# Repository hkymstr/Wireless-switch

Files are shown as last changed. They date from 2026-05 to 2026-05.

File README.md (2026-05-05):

# Wireless Race Car Switch System — Hardware v2 (WiFi)

A fully wireless switch panel for a race car using two **Raspberry Pi Pico 2 W** boards.  
One board acts as the **Transmitter** (switch panel), the other as the **Receiver** (12 V output driver).

> **Bluetooth version:** see the `bluetooth` branch.

---

## System Overview

```
 ┌──────────────────────────┐      WiFi (AP/STA)      ┌─────────────────────────────┐
 │      TRANSMITTER         │ ◄──── UDP 20 Hz ──────► │        RECEIVER             │
 │    Raspberry Pi Pico 2W  │                          │    Raspberry Pi Pico 2W     │
 │                          │  Web UI: 192.168.4.1     │  Web UI: <RX-IP>            │
 │  GPIO 1-5 ← 5 switches   │                          │  GPIO 8-11 → 4× MOSFET     │
 │  GPIO 0  → Connected LED │                          │  GPIO 12   → Relay K2      │
 │  GPIO 7  → Searching LED │                          │  GPIO 0    → Connected LED  │
 │  Powered from 12 V via   │                          │  GPIO 7    → Searching LED  │
 │  on-board 5 V regulator  │                          │  Takes 12 V from car        │
 └──────────────────────────┘                          └─────────────────────────────┘
```

TX creates an **open WiFi access point** (`WirelessSwitch-1` by default). RX connects as a station.  
Both boards host a **web settings page** — join the WiFi network and open a browser to configure.

---

## Web Interface

| Board | URL | What you can change |
|---|-----|---|
| TX | `http://192.168.4.1` | Pair ID |
| RX | `http://<RX-IP>` (linked from TX page) | Pair ID, hold time, channel modes |

Connect any phone or laptop to the `WirelessSwitch-N` WiFi network (no password), then open the URL above. Settings are saved to flash and survive power cycles.

---

## GPIO Pin Mapping — Hardware v2

### Status LEDs (identical on both boards)

| GPIO | Function | Behaviour |
|---|---|---|
|  0 | CONNECTED LED | Solid ON when wireless link is up |
|  7 | SEARCHING LED | Flashes 2 Hz while searching; OFF when linked |

### Transmitter — Switch Inputs

Switches are **active-low** (connect switch between GPIO pin and GND).  
Internal pull-ups enabled in firmware.

| GPIO | Channel | Description |
|---|---|---|
|  1 | SW1 | Switch 1 input |
|  2 | SW2 | Switch 2 input |
|  3 | SW3 | Switch 3 input |
|  4 | SW4 | Switch 4 input |
|  5 | SW5 | Switch 5 input |

### Receiver — Output Channels

Outputs are **active-high** (GPIO HIGH = output energised).

| GPIO | Channel | Type | Max Load |
|---|---|---|---|
|  8 | CH1 | N-ch MOSFET | 5 A @ 12 V |
|  9 | CH2 | N-ch MOSFET | 5 A @ 12 V |
| 10 | CH3 | N-ch MOSFET | 5 A @ 12 V |
| 11 | CH4 | N-ch MOSFET | 5 A @ 12 V |
| 12 | CH5 | Relay K2 (SPDT) | Per relay rating |

---

## Repository Structure

```
├── kicad/
│   ├── wireless_switch.kicad_pro   KiCad project file
│   ├── wireless_switch.kicad_sch   Top-level schematic
│   ├── Pico_interface.kicad_sch    Pico 2 W GPIO interface sub-sheet
│   ├── analog_in.kicad_sch         Output channel sub-sheet (MOSFET + relay)
│   ├── input_power.kicad_sch       12 V → 5 V power supply sub-sheet
│   ├── wireless_switch.kicad_pcb   PCB layout
│   └── sym-lib-table               KiCad symbol library table
│
├── firmware/
│   ├── config.py        Shared configuration (defaults – overridden by web UI)
│   ├── tx_main.py       Transmitter MicroPython firmware
│   ├── rx_main.py       Receiver MicroPython firmware
│   ├── install_tx.bat   Windows transmitter installer  (default COM3)
│   ├── install_rx.bat   Windows receiver installer     (default COM5)
│   ├── install_tx.sh    Linux / macOS transmitter installer
│   ├── install_rx.sh    Linux / macOS receiver installer
│   ├── verify.bat       18-point verification script (Windows)
│   ├── led_test.bat     LED blink test (Windows)
│   └── polarity_test.bat  LED polarity / GPIO finder (Windows)
│
└── docs/
    └── wireless_switch.pdf   Full schematic PDF
```

---

## Hardware Requirements

### Per Board (× 2)
- Raspberry Pi Pico 2 W
- PCB from `kicad/wireless_switch.kicad_pcb`

### Transmitter PCB BOM additions
- 5× panel-mount toggle switches (SPDT or SPST)
- 2× LEDs with 330 Ω series resistors for GPIO 0 & 7
- 12 V → 5 V onboard regulator + capacitors (see `input_power.kicad_sch`)

### Receiver PCB BOM additions
- 4× N-channel logic-level MOSFETs (e.g. IRLZ44N) with gate resistors
- 1× 12 V SPDT relay K2 (Omron G5V-1 or equivalent)
- Relay driver transistor + flyback diodes
- Fusing on each output channel

---

## Software Installation

### Step 1 — Flash MicroPython to each Pico 2 W

1. Download the **Pico 2 W** MicroPython UF2 from  
   `https://micropython.org/download/RPI_PICO2_W/`
2. Hold **BOOTSEL**, plug USB → Pico appears as `RPI-RP2` mass storage
3. Drag the `.uf2` onto the drive — Pico reboots automatically

### Step 2 — Install `mpremote`

```bash
pip install mpremote
```

### Step 3 — Install Transmitter firmware

**Windows** (default COM3):
```bat
cd firmware
install_tx.bat
install_tx.bat COM4    ← specify a different port if needed
```

**Linux / macOS:**
```bash
cd firmware
chmod +x install_tx.sh && ./install_tx.sh
```

Confirm: board blinks SEARCHING LED **3× quickly** then flashes slowly.

### Step 4 — Install Receiver firmware

**Windows** (default COM5):
```bat
install_rx.bat
```

**Linux / macOS:**
```bash
./install_rx.sh
```

### Step 5 — Verify (optional, Windows)

```bat
verify.bat COM3 COM5
led_test.bat COM3 COM5
```

---

## Operation

1. **Power on both boards.** Both blink the SEARCHING LED **3× quickly** to confirm firmware is running.
2. TX creates an open WiFi access point. Both boards flash their SEARCHING LED while waiting for a link.
3. Once linked, **CONNECTED LED turns solid** on both boards; SEARCHING LED turns off.
4. Pressing a switch on TX activates the corresponding output on RX according to that channel's mode.
5. **On link loss:** RX holds its last output states for the configured hold time (default 10 s), then turns all outputs off. Both boards resume searching.

### Link Parameters

| Parameter | Value |
|---|---|
| Update rate | 20 Hz (every 50 ms) |
| Link timeout | 2 s |
| Hold on disconnect  | 10 s (configurable) |
| Protocol | UDP port 4210 |
| WiFi mode | TX = AP, RX = Station  |
| Network | Open (no password) |

---

## Channel Modes

Each output channel can be set independently via the RX web interface:

| Mode | Behaviour |
|---|---|
| Momentary | Output ON while switch is held; OFF when released |
| Latch | First press turns output ON; next press turns it OFF |

Latch state is preserved through brief disconnects (within hold window).  
A disconnection longer than the hold time resets all latch states to OFF.

---

## Multiple Pairs

If two TX/RX pairs operate at the same time, each pair needs a unique **Pair ID** so they don't cross-connect.

Set the same Pair ID on both boards in a pair via the web interface:

| Pair | TX SSID | RX connects to  |
|---|---|---|
|  1 | WirelessSwitch-1 | WirelessSwitch-1 |
|  2 | WirelessSwitch-2 | WirelessSwitch-2 |

**Procedure for changing Pair ID:**
1. Connect to the current WiFi network
2. Open RX settings → change Pair ID → Save (RX reboots, now looks for new SSID)
3. Open TX settings (192.168.4.1) → change Pair ID → Save (TX reboots with new SSID)
4. RX reconnects automatically

---

## Troubleshooting

| Symptom | Likely cause | Fix |
|---|---|-----|
| No 3× startup blink | Firmware not installed | Re-run the installer; verify MicroPython UF2 was flashed first |
| SEARCHING LED never stops flashing | Wrong Pair ID or TX not powered | Check both boards have the same Pair ID; confirm TX SEARCHING LED is also flashing |
| TX AP has stale WPA2 password | Old security settings cached in chip | Firmware resets the AP before configuring — power-cycle TX |
| Can't open web interface | Not connected to WirelessSwitch-N WiFi | Join the WiFi network first (no password), then open the URL |
| RX web page not reachable | RX IP unknown | Open TX page (192.168.4.1) first — it shows a clickable link to the RX page |
| Outputs don't activate | Wrong firmware on board | Confirm TX has `tx_main.py` installed as `main.py` |
| Latch output stuck after reboot | Expected — latch state is in RAM only | Press the switch once to toggle off |
| `mpremote` cannot find device | Driver missing or wrong port | Run `python -m mpremote connect list` |
| Pico not detected as storage | Not holding BOOTSEL | Hold BOOTSEL before plugging USB |

---

## Protocol Reference

UDP packet format (7 bytes, TX → RX, port 4210):

```
Byte 0   : 0xAA  (start marker)
Byte 1   : Switch 1 state  (0 = open, 1 = pressed)
Byte 2   : Switch 2 state
Byte 3   : Switch 3 state
Byte 4   : Switch 4 state
Byte 5   : Switch 5 state
Byte 6   : Checksum  = (SW1+SW2+SW3+SW4+SW5) & 0xFF
```

RX → TX heartbeat: `b"RXHERE"` (6 bytes, every 50 ms) — tells TX the RX's IP address.

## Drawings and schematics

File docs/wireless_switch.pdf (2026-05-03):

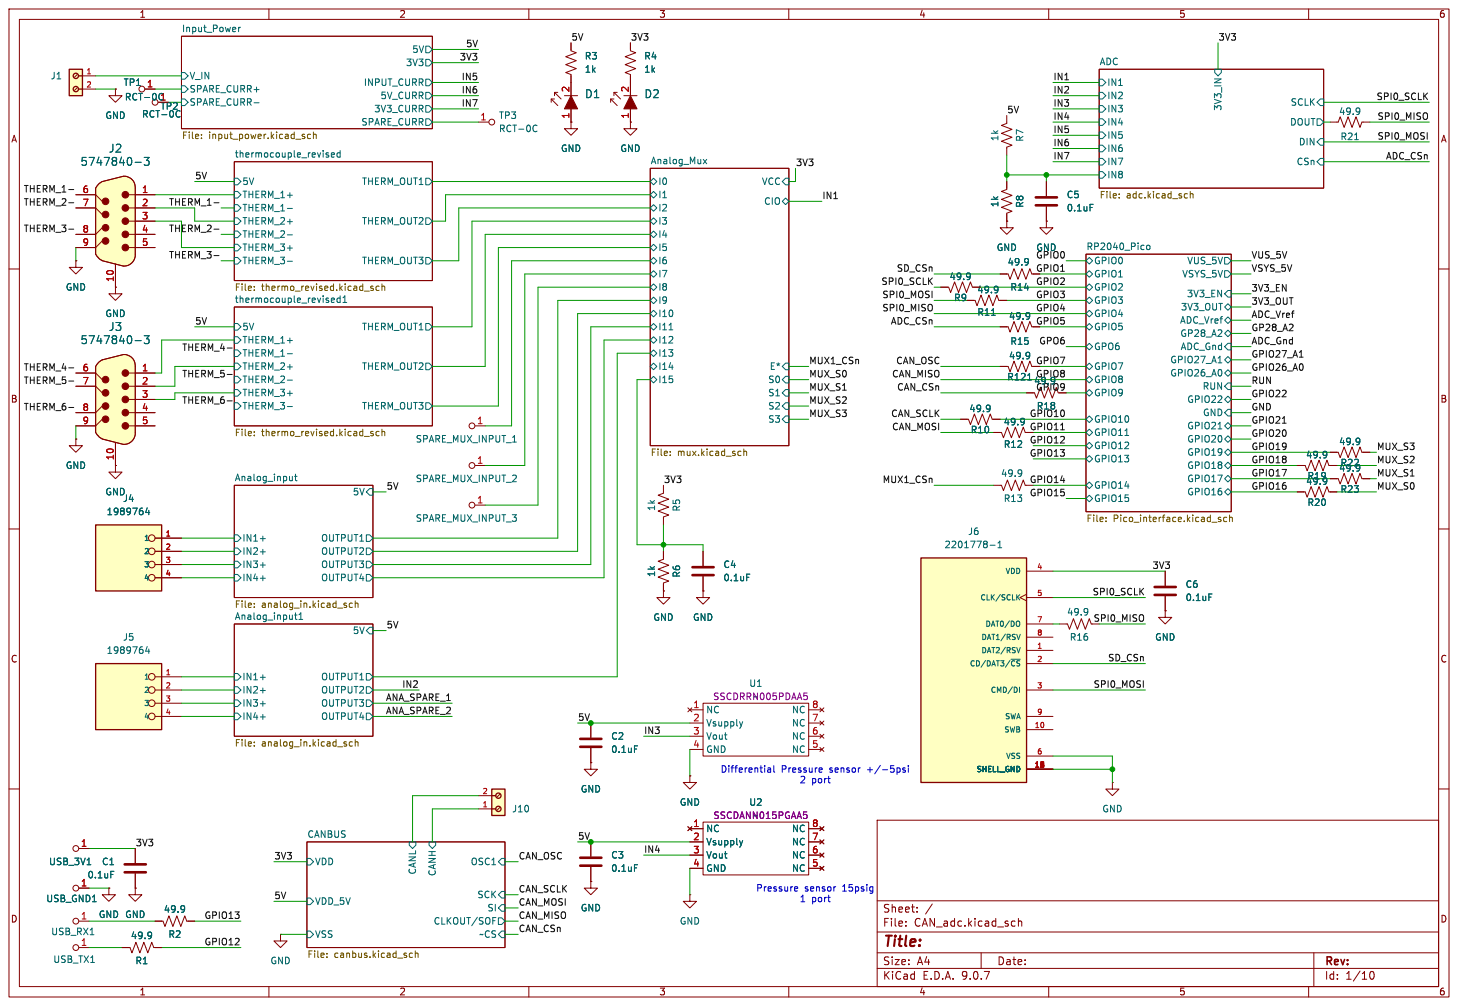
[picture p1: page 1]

Id: 1/10 Title: File: CAN_adc.kicad_sch Sheet: /

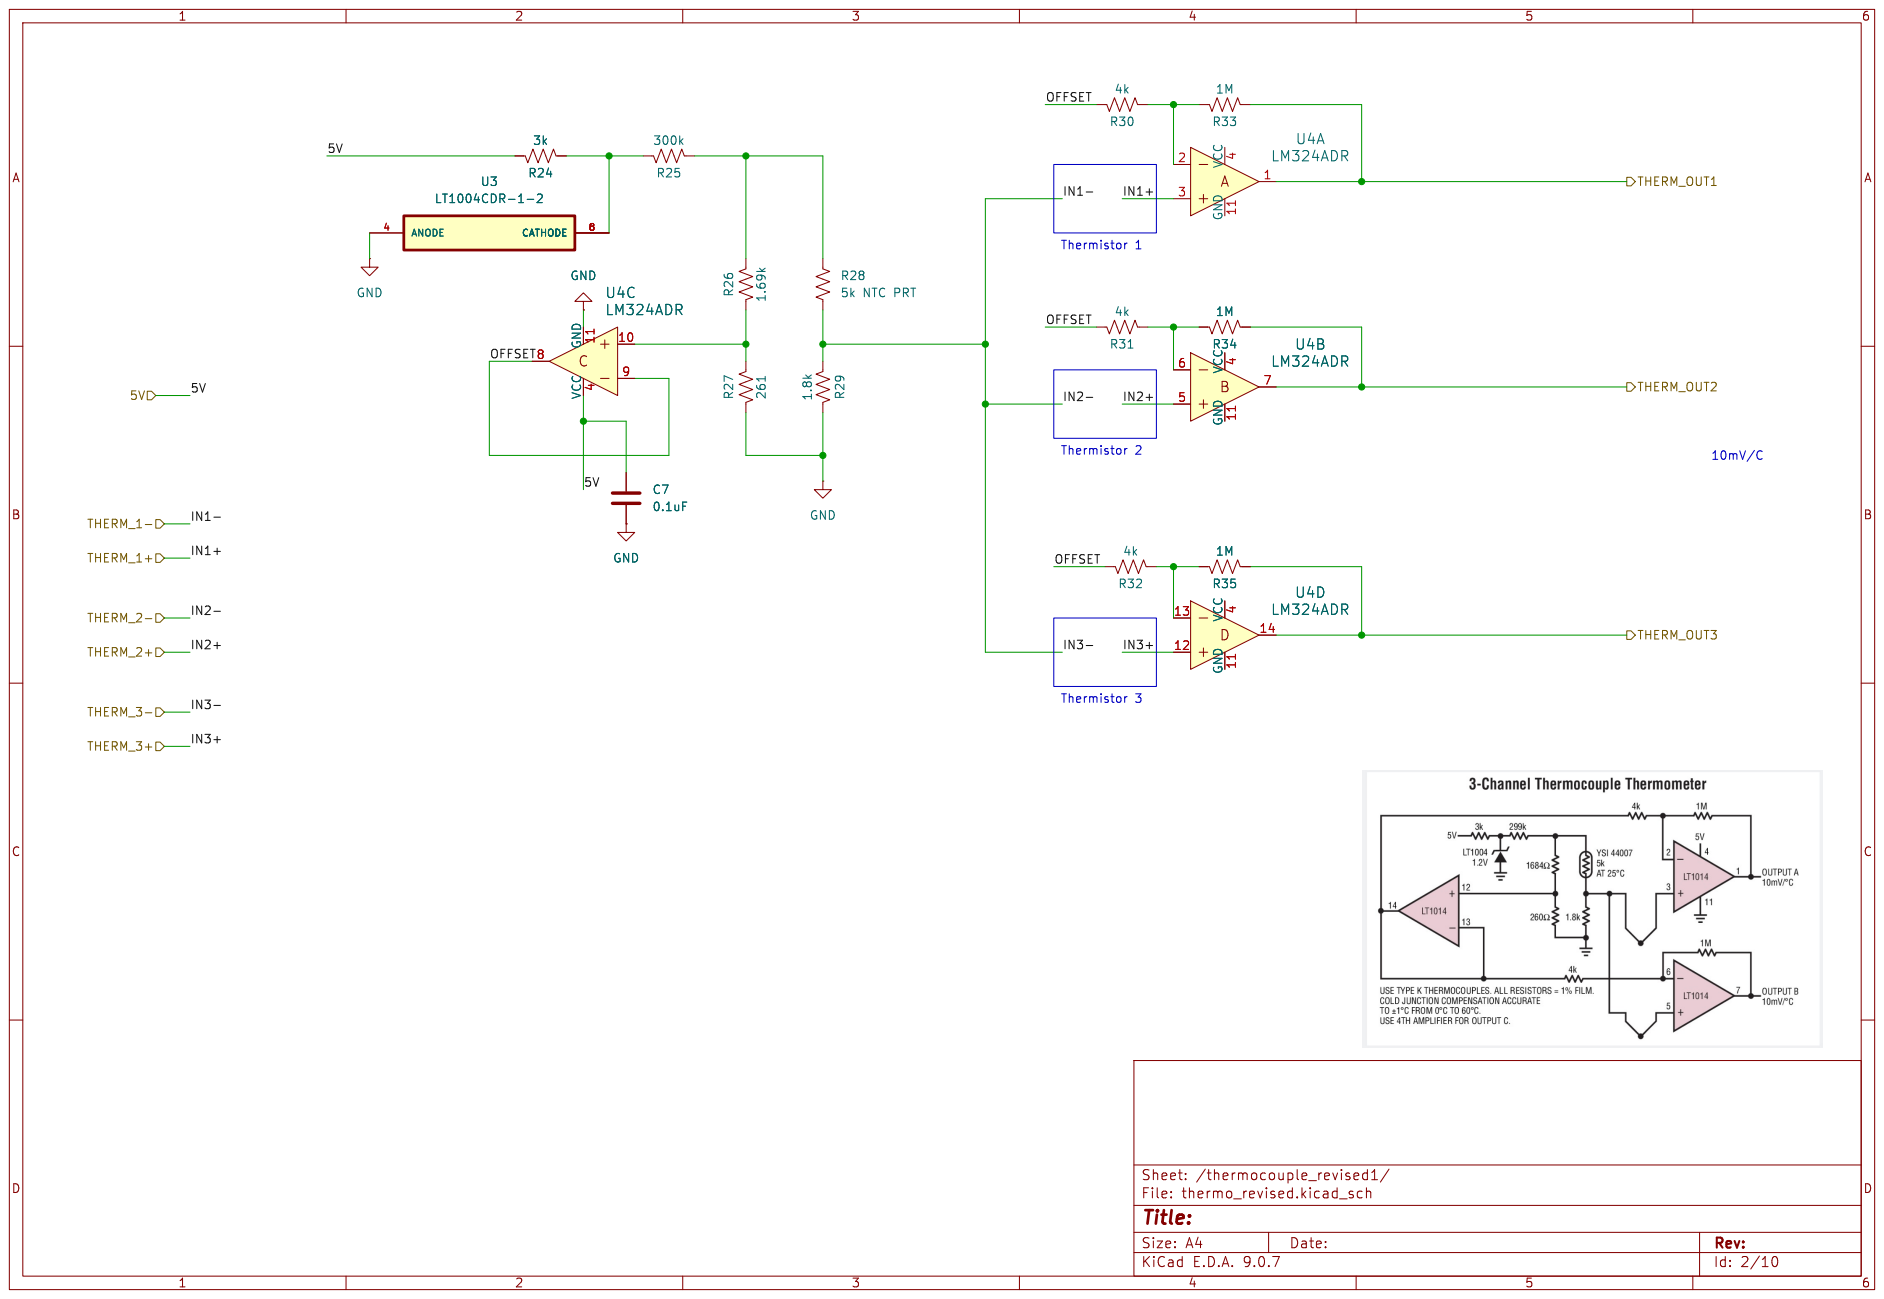
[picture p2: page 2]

Id: 2/10 Title: File: thermo_revised.kicad_sch Sheet: /thermocouple_revised1/

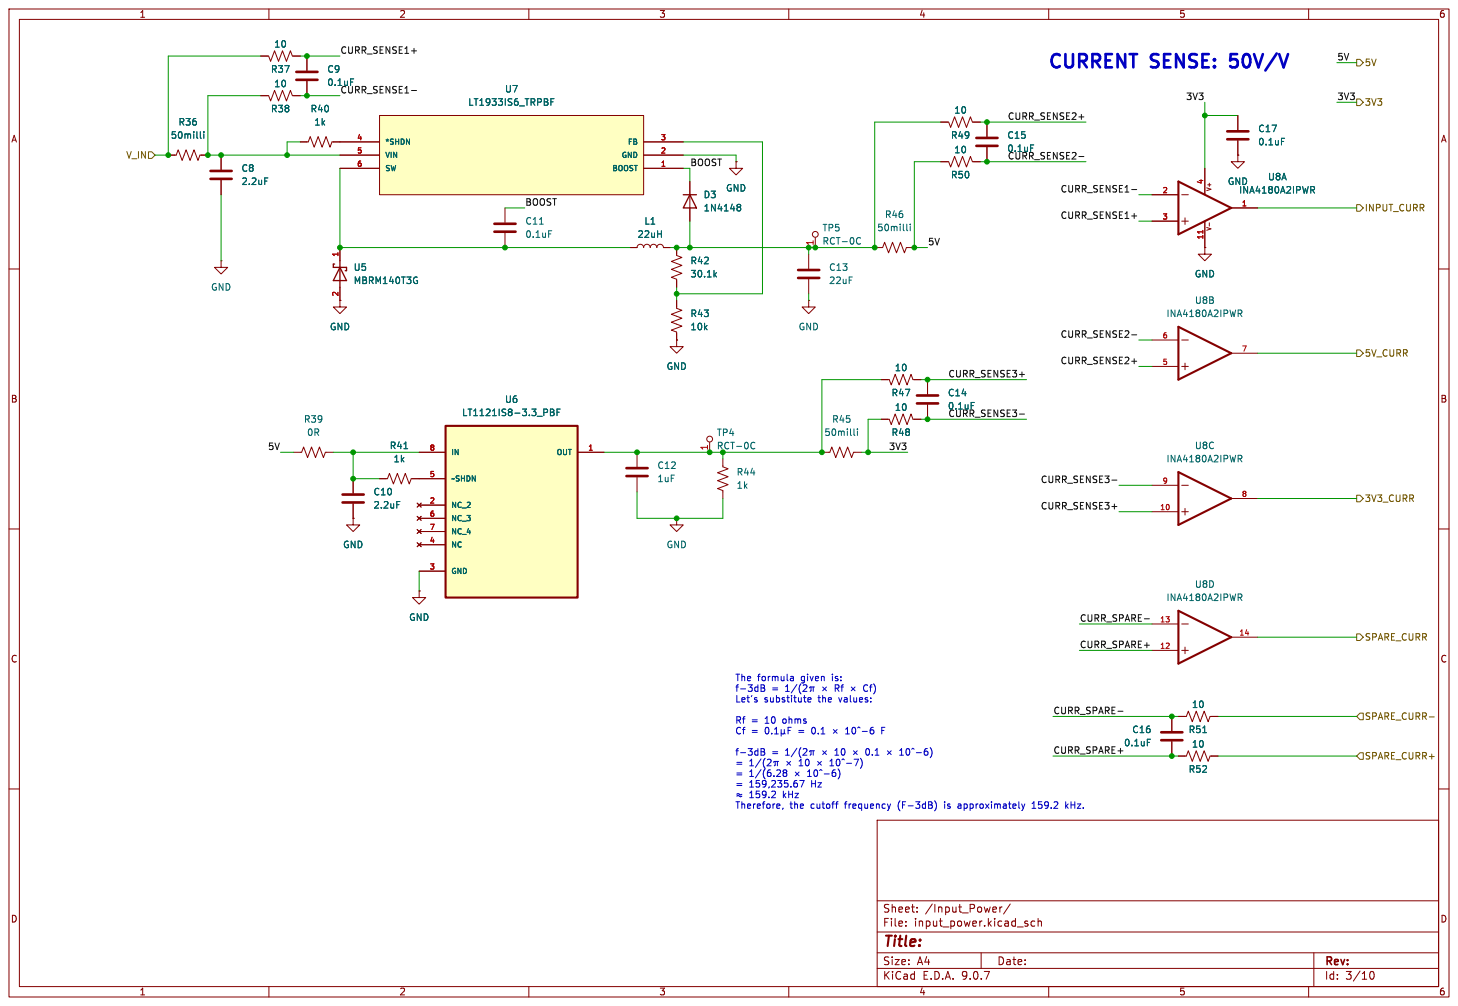
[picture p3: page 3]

Id: 3/10 Title: File: input_power.kicad_sch Sheet: /Input_Power/

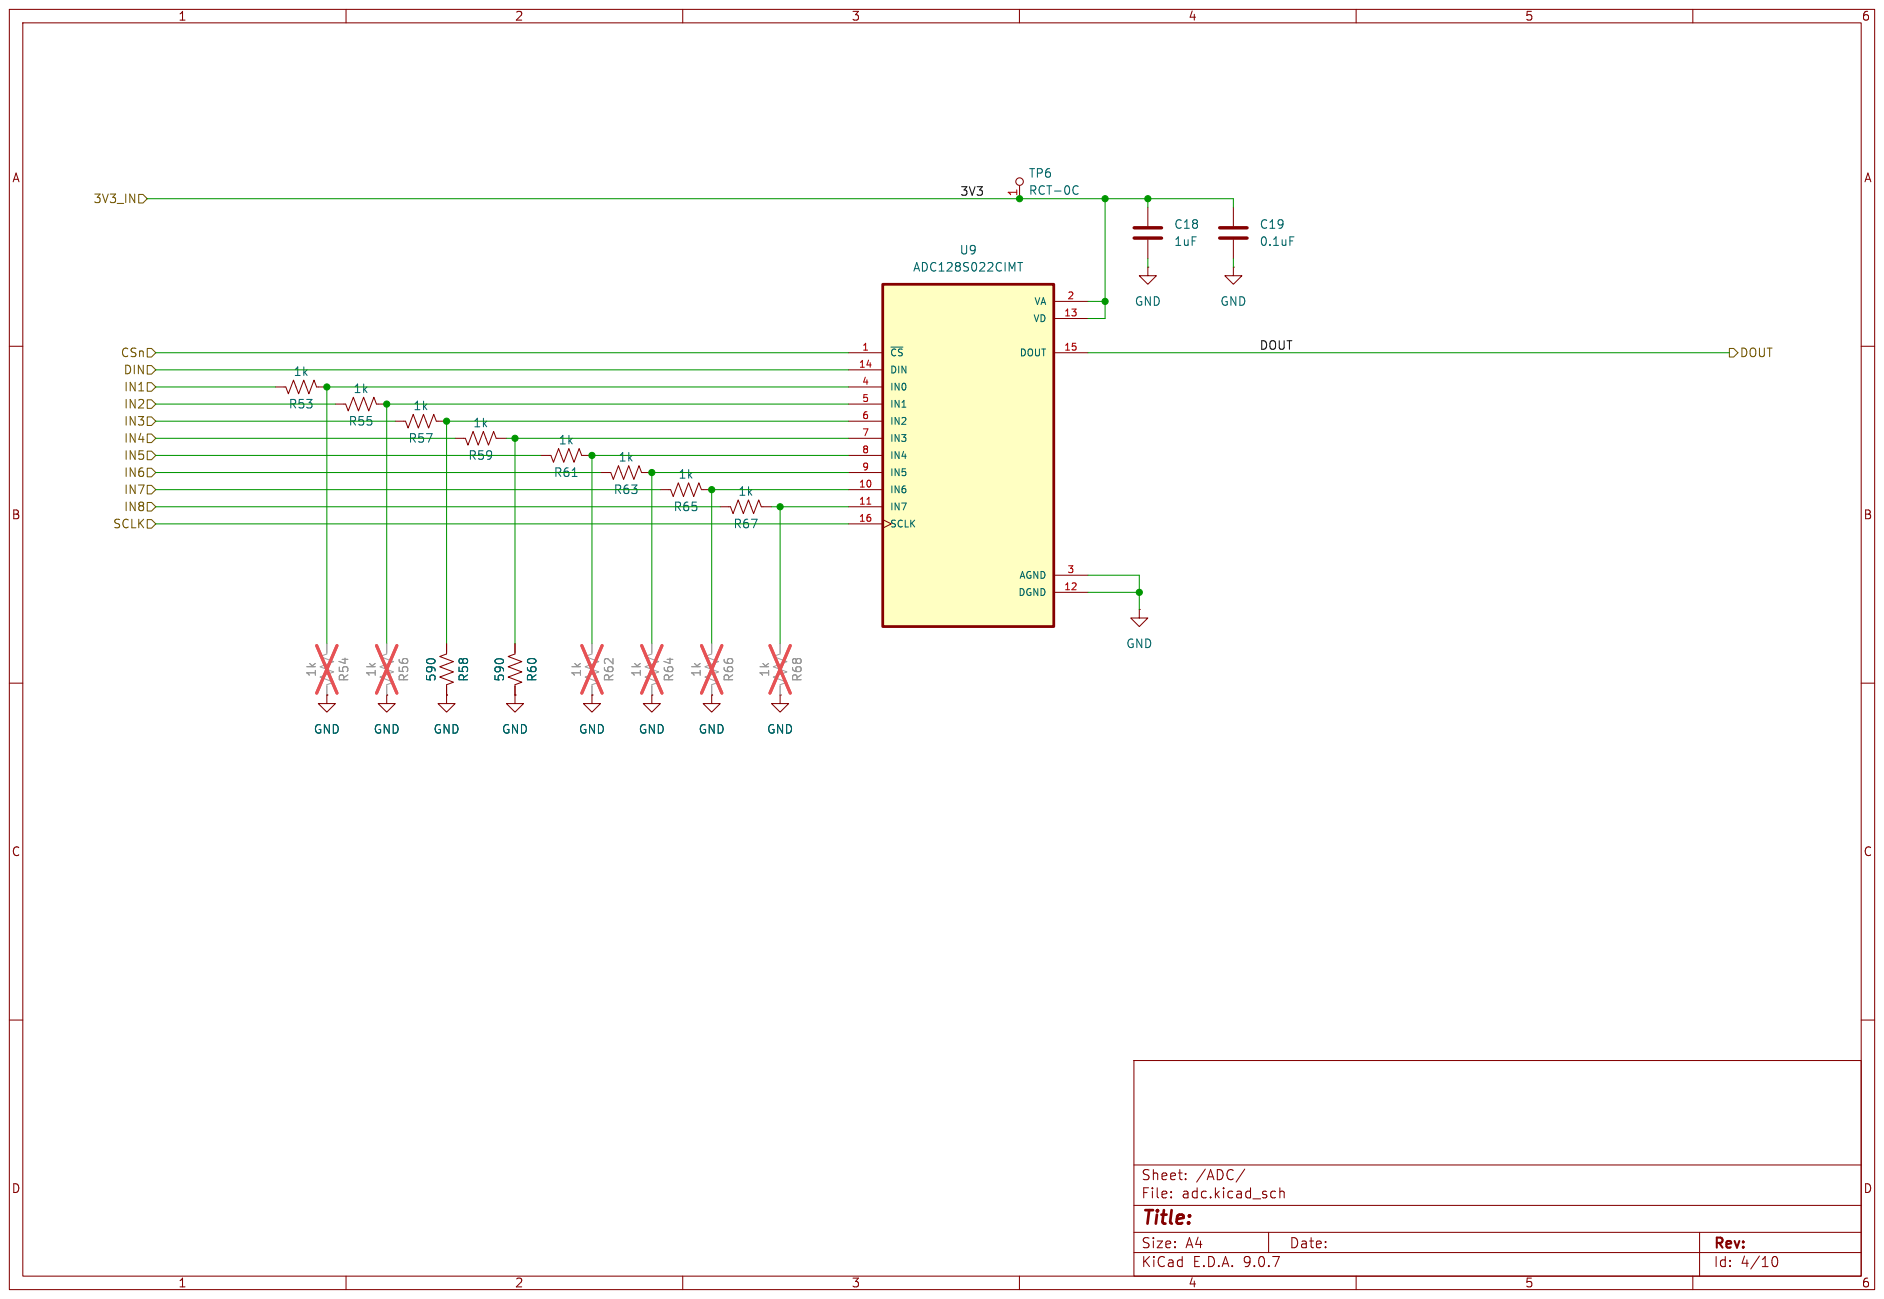
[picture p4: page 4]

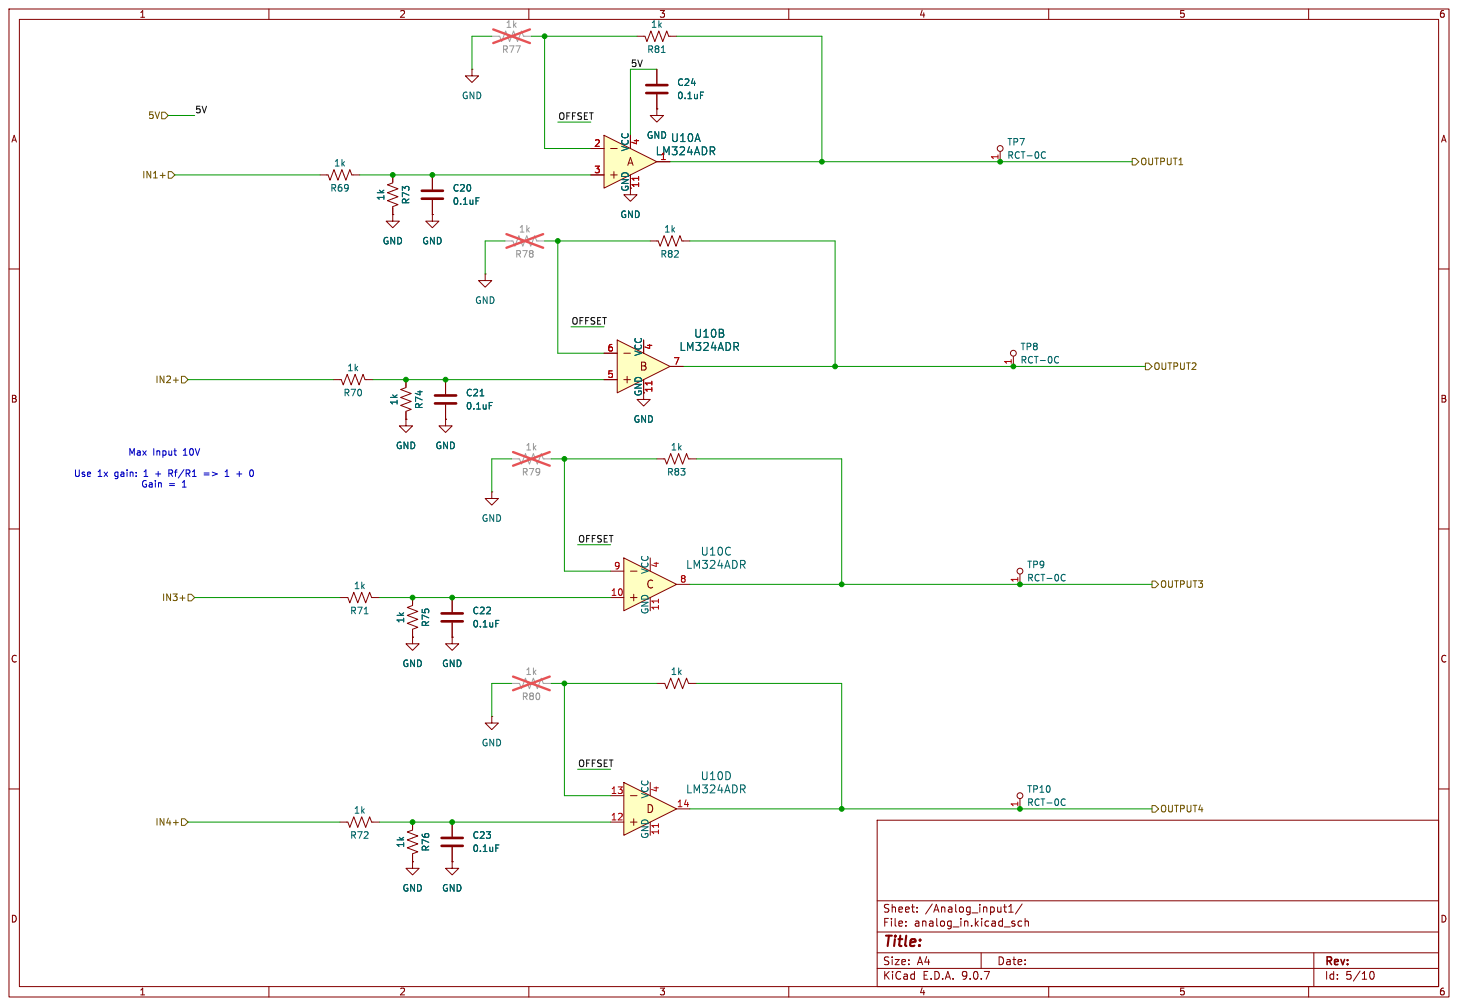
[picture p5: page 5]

Id: 5/10 Title: File: analog_in.kicad_sch Sheet: /Analog_input1/ 1k R72

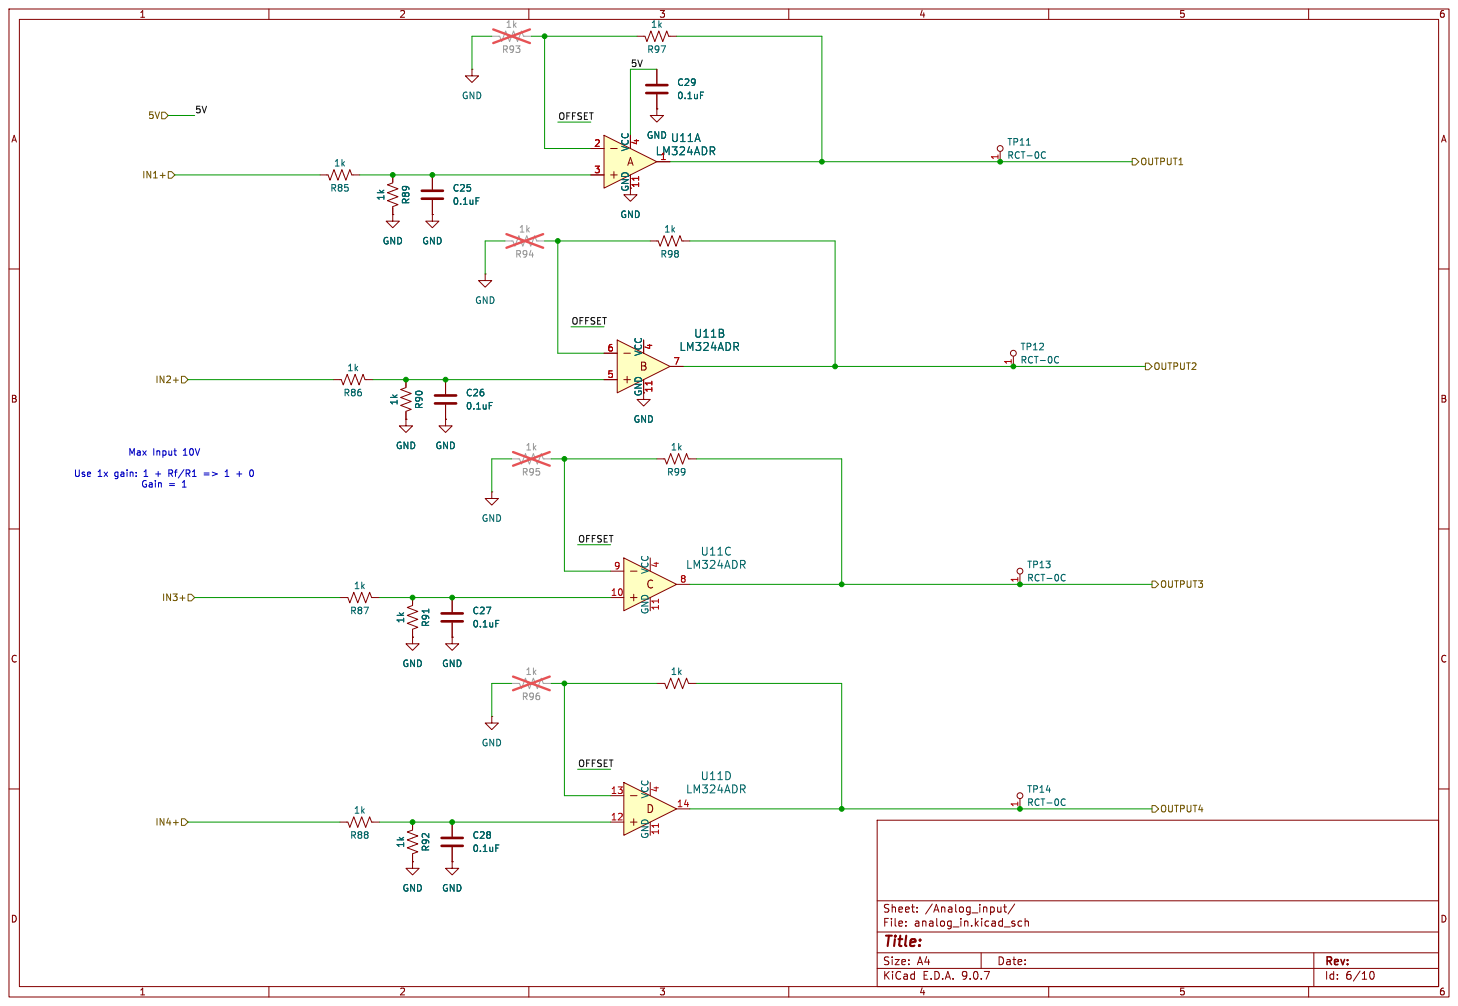
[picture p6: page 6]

Id: 6/10 Title: File: analog_in.kicad_sch Sheet: /Analog_input/ C 9

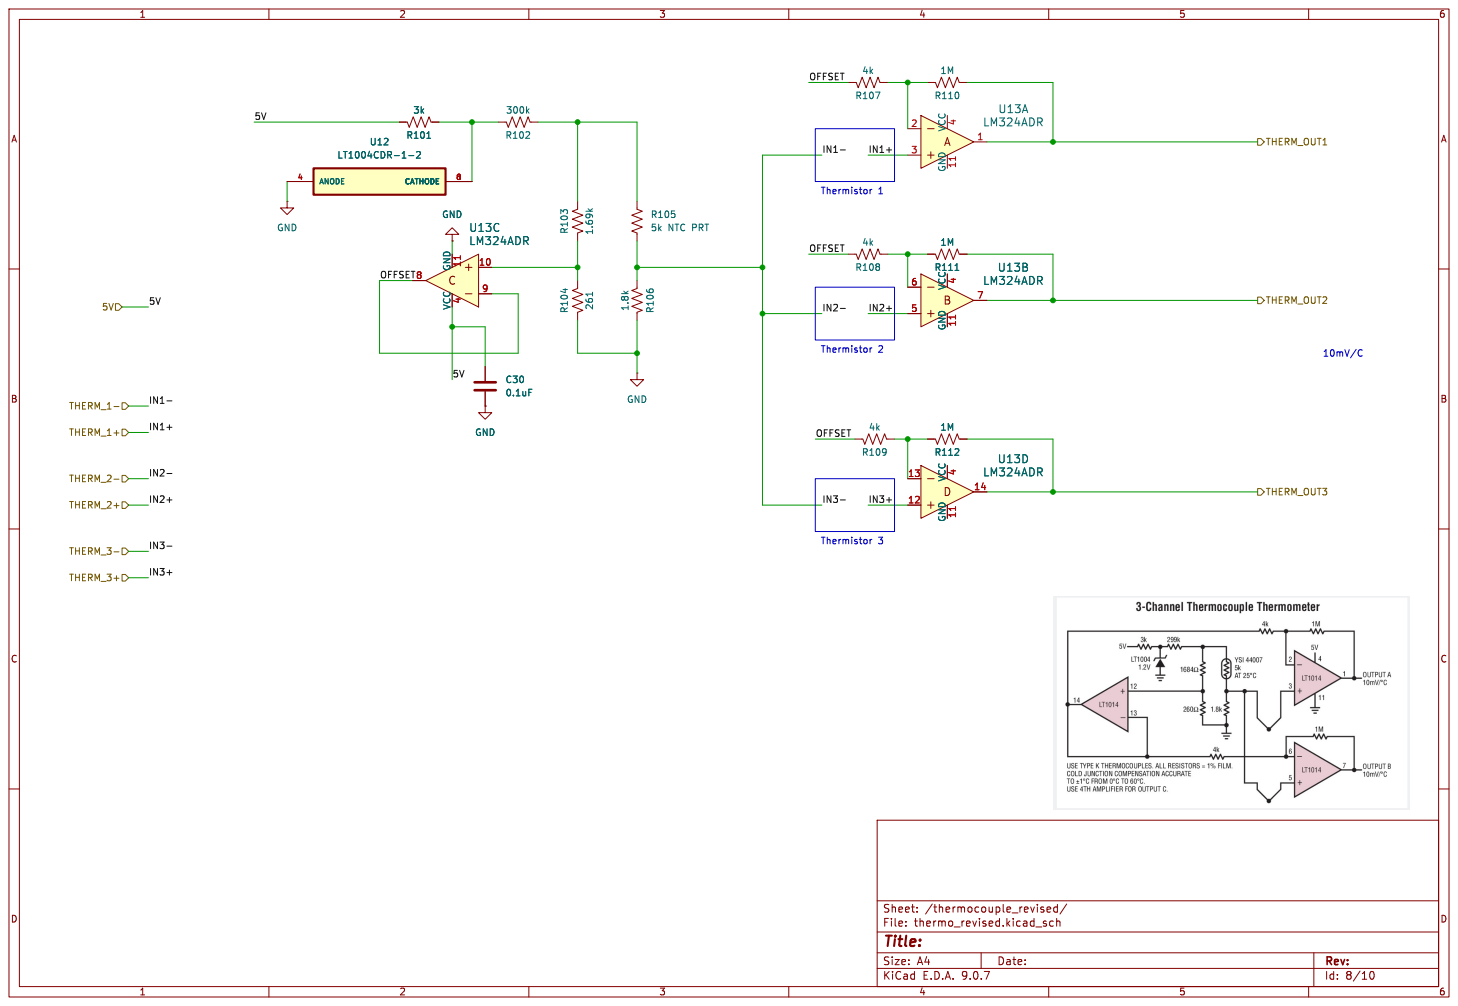
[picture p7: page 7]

Id: 8/10 Title: File: thermo_revised.kicad_sch Sheet: /thermocouple_revised/

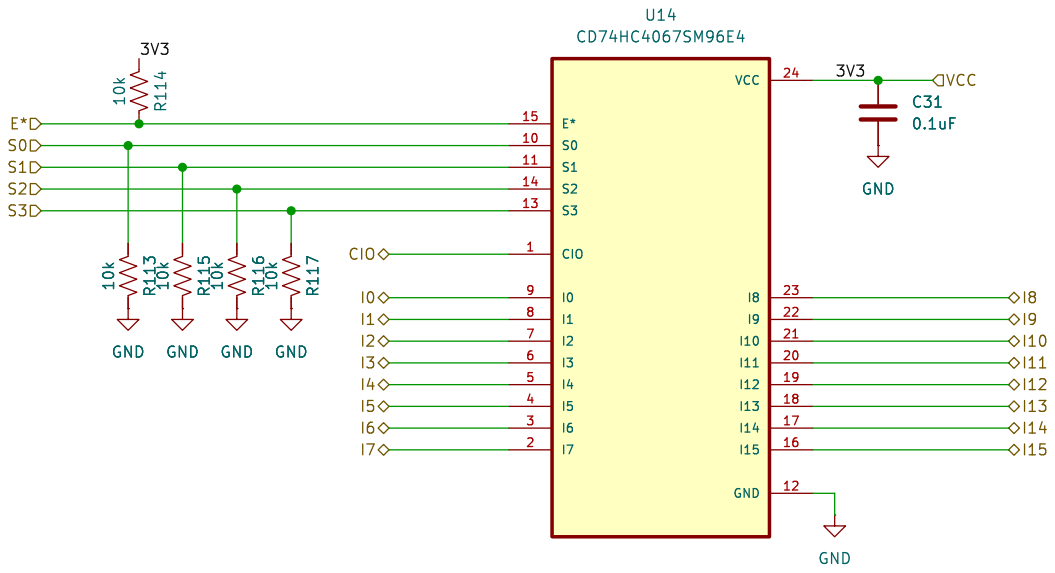
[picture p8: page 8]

Id: 9/10 Title: File: mux.kicad_sch Sheet: /Analog_Mux/ GND

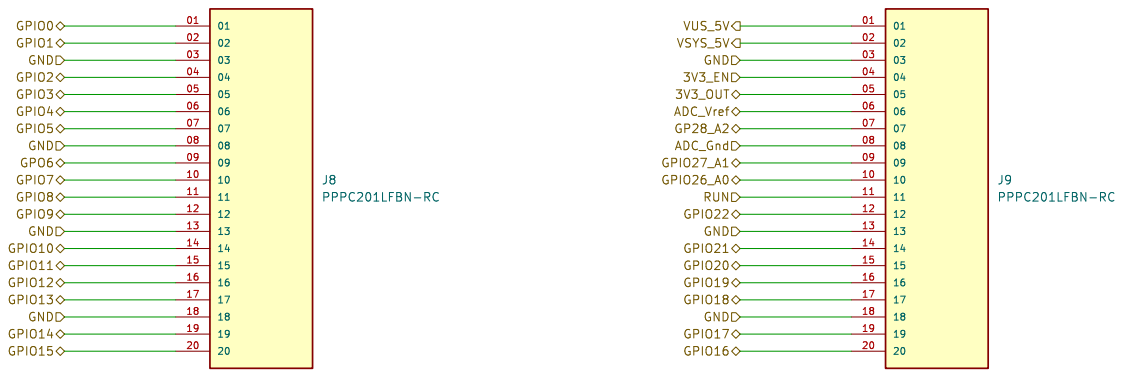
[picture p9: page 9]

3V3_OUT ADC_Vref VUS_5V GPIO16 GPIO18 GND GPIO17 GPIO19 GPIO20 GPIO21 GPIO3 GPIO15 GPIO10 GPIO12 GPIO13 GPIO14 GPIO11 GND GPIO5 GPIO2 GND GPIO4 GPIO1 GPIO0 GND GND GPIO8 GPO6 GPIO7

Id: 9/10 Title: File: Pico_interface.kicad_sch Sheet: /RP2040_Pico/

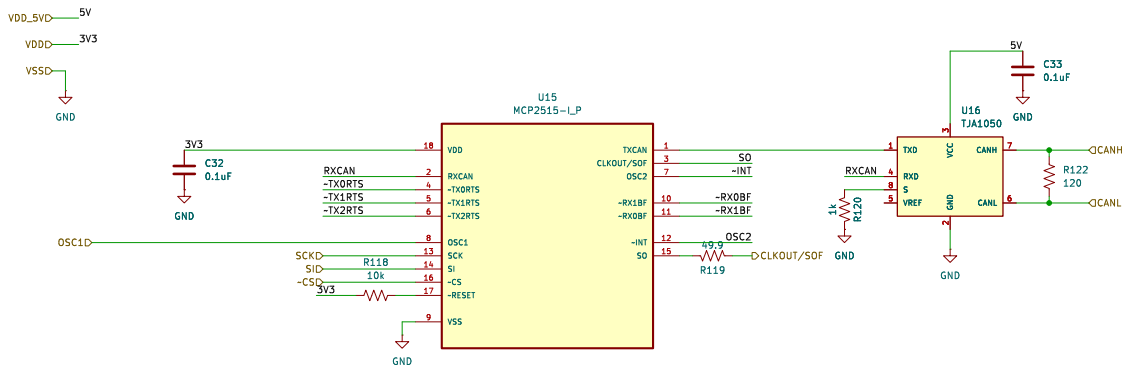
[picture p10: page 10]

2 CANH 7 CANL 6 U16 TJA1050 GND R120 1k GND

Id: 10/10 Title: File: canbus.kicad_sch Sheet: /CANBUS/ GND

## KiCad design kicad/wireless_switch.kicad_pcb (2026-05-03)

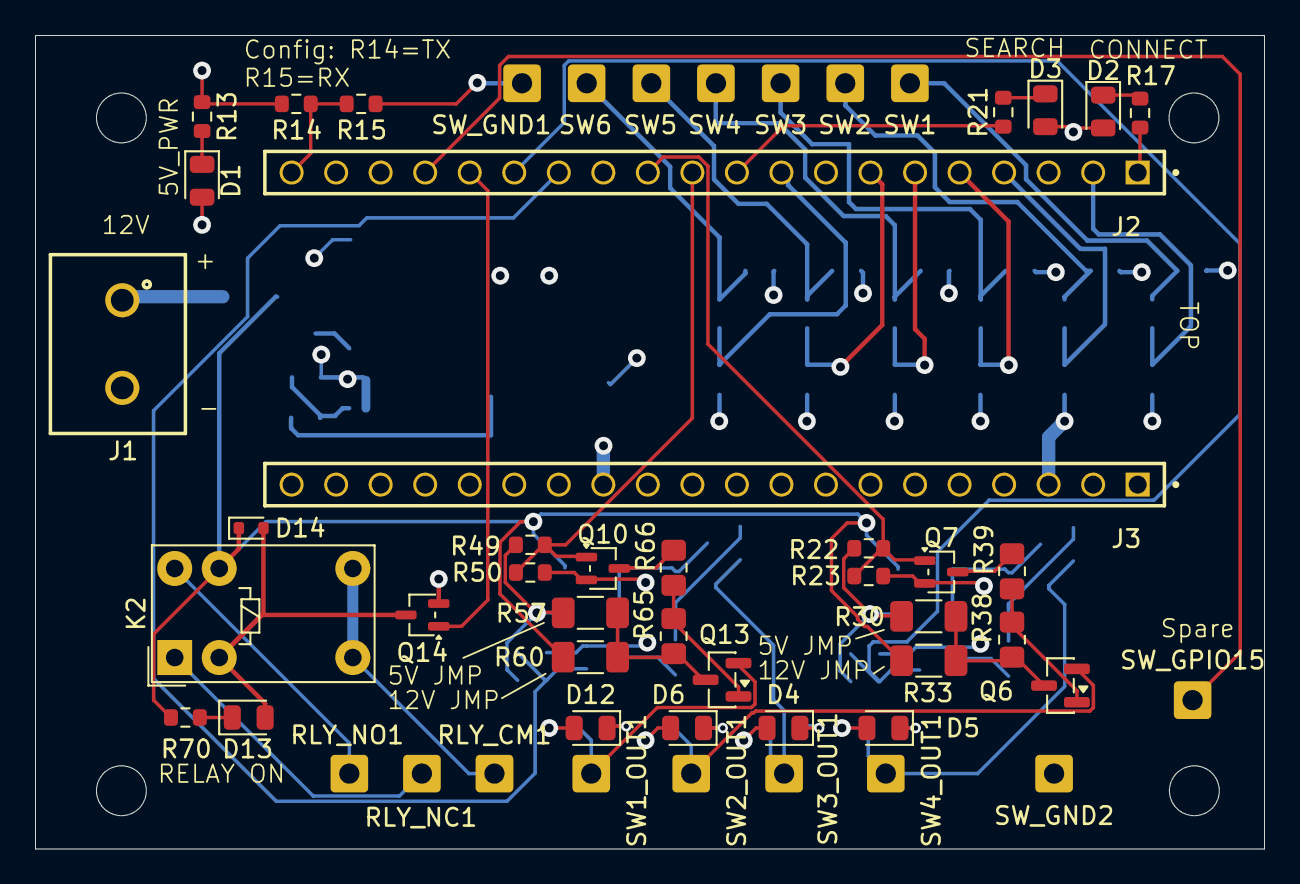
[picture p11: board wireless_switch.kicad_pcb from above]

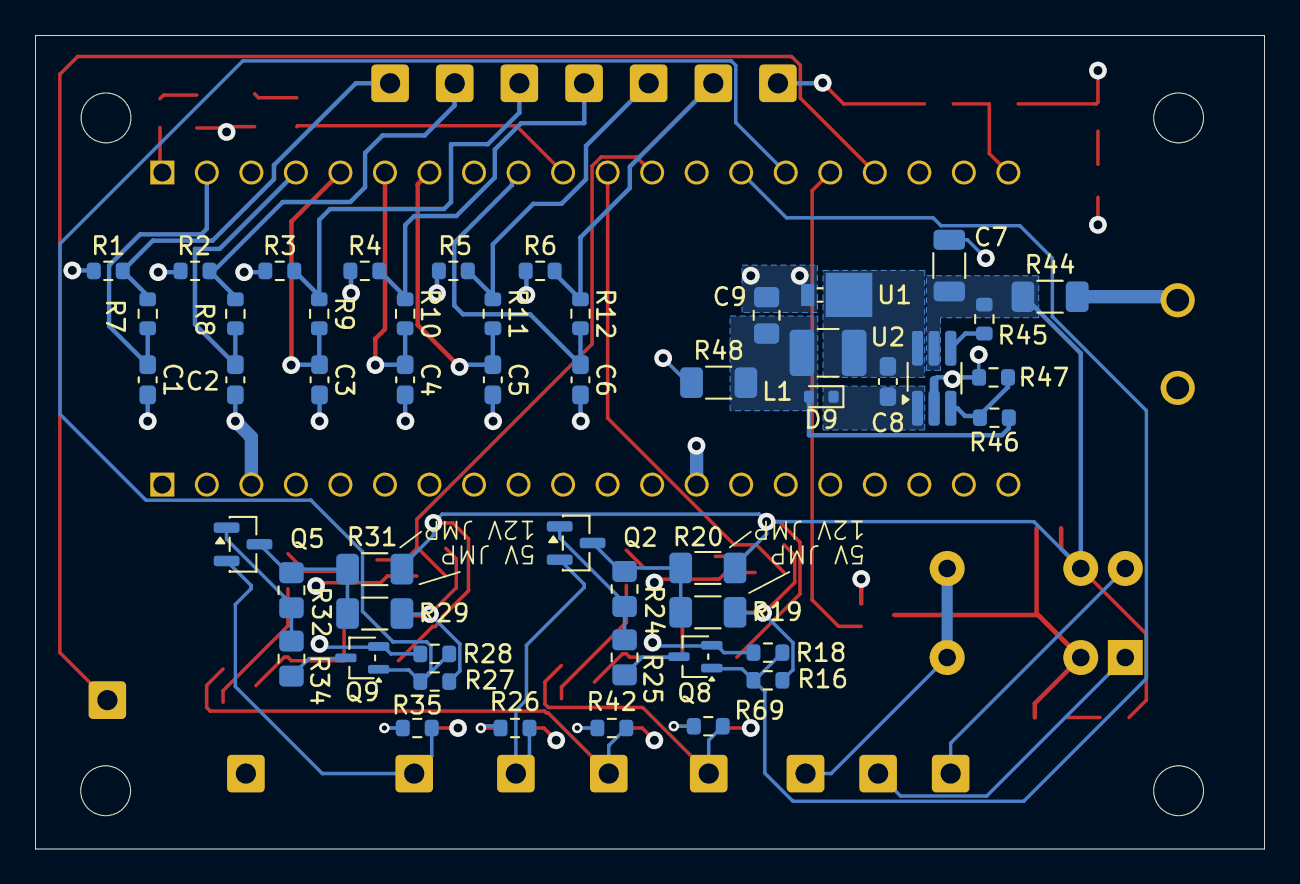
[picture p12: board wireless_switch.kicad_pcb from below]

Board: 4 copper layers, 70.1 x 46.4 mm, 102 parts (50 on the bottom side), 58 nets.

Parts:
C1, C2, C3, C4, C5, C6, C8: 0.1uF; C_0603_1608Metric_Pad1.08x0.95mm_HandSolder
C7: 2.2uF; C_1206_3216Metric
C9: 22uF; C_0805_2012Metric_Pad1.18x1.45mm_HandSolder
D1, D2, D3, D4, D5, D6, D12, D13: LTST-C171KGKT; LED_0805_2012Metric
D9, D14: 1N4148; D_SOD-523
J1: 691137710002
J2, J3: PPPC201LFBN-RC; SAMTEC_ESQ-120-24-G-S
K2: G5V-1; Relay_SPDT_Omron_G5V-1
L1: 22uH; L_1210_3225Metric_Pad1.42x2.65mm_HandSolder
Q2, Q5, Q6, Q13: MOSFET P-CH 30V; SOT-23
Q7, Q8, Q9, Q10: MOSTFET N-CH 50V; SOT-323_SC-70
Q14: Q_NMOS_GSD; SOT-323_SC-70
R1, R2, R3, R4, R5, R6, R13, R14, R15, R16, R17, R18, R21, R22, R23, R26, R27, R28, R35, R42, R45, R49, R50, R69, R70: 1k; R_0603_1608Metric
R7, R8, R9, R10, R11, R12, R47: 10k; R_0603_1608Metric
R19, R20, R29, R30, R31, R33, R44, R48, R57, R60: 50milli; R_1206_3216Metric_Pad1.30x1.75mm_HandSolder
R24, R25, R32, R34, R38, R39, R65, R66: 1k; R_0805_2012Metric_Pad1.20x1.40mm_HandSolder
R46: 30.1k; R_0603_1608Metric
RLY_CM1: RCT-0C; SolderWire-0.5sqmm_1x01_D0.9mm_OD2.1mm
RLY_NC1: RCT-0C; SolderWire-0.5sqmm_1x01_D0.9mm_OD2.1mm
RLY_NO1: RCT-0C; SolderWire-0.5sqmm_1x01_D0.9mm_OD2.1mm
SW1, SW1_OUT1, SW2, SW2_OUT1, SW3, SW3_OUT1, SW4, SW4_OUT1, SW5, SW6: RCT-0C; SolderWire-0.5sqmm_1x01_D0.9mm_OD2.1mm
SW_GND1, SW_GND2: RCT-0C; SolderWire-0.5sqmm_1x01_D0.9mm_OD2.1mm
SW_GPIO15: RCT-0C; SolderWire-0.5sqmm_1x01_D0.9mm_OD2.1mm
U1: MBRM140T3G; D_Powermite_AK
U2: LT1933IS6_TRPBF; TSOT-23-6_HandSoldering

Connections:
/5V: R1.1, R2.1, R3.1, R4.1, R5.1, R6.1, R13.1, R14.1, R16.1, R19.1, R22.1, R27.1, R29.1, R30.1, R48.1, R49.1, R57.1
/12V_FILT: C7.1, D14.1 (K), K2.9, R20.1, R31.1, R33.1, R44.1, R45.2, R60.1, R70.1, U2.5 (VIN)
/CONNECTED: J2.01, R17.1
/GPIO1: C1.1, J2.02, R7.2
/GPIO2: C2.1, J2.04, R8.2
/GPIO3: C3.1, J2.05, R9.2
/GPIO4: C4.1, J2.06, R10.2
/GPIO5: C5.1, J2.07, R11.2
/GPIO6: C6.1, J2.09, R12.2
/GPIO7: J2.10, R21.1
/GPIO8: J2.11, Q10.1 (G), R49.2, R50.1
/GPIO9: J2.12, Q7.1 (G), R22.2, R23.1
/GPIO10: J2.14, Q8.1 (G), R16.2, R18.1
/GPIO11: J2.15, Q9.1 (G), R27.2, R28.1
/GPIO12: J2.16, Q14.1 (G)
/GPIO13: J2.17, SW_GPIO15.1
/GPIO15: J2.20, R14.2, R15.1
/Input_Power/BOOST: C8.1, D9.1 (K), U2.1 (BOOST)
/Input_Power/V_IN: J1.1, R44.2
/OUTPUT_CIRCUIT1/OUT1+: Q6.2 (S), R42.1, SW2_OUT1.1
/OUTPUT_CIRCUIT2/OUT1+: Q2.2 (S), R26.1, SW3_OUT1.1
/OUTPUT_CIRCUIT3/OUT1+: Q5.2 (S), R35.1, SW4_OUT1.1
/OUTPUT_CIRCUIT/OUT1+: Q13.2 (S), R69.1, SW1_OUT1.1
/RELAY_GND: D13.2, D14.2 (A), K2.2, Q14.3 (D)
GND: C1.2, C2.2, C3.2, C4.2, C5.2, C6.2, C7.2, C9.2, D1.2, D2.2, D3.2, D4.2, D5.2, D6.2, D12.2, J1.2, J2.03, J2.08, J2.13, J2.18, J3.03, J3.13, J3.18, Q7.2 (S), Q8.2 (S), Q9.2 (S), Q10.2 (S), Q14.2 (S), R15.2, R18.2, R23.2, R28.2, R47.2, R50.2, SW_GND1.1, SW_GND2.1, U1.2, U2.2 (GND)
unnamed: D1.1, R13.2
unnamed: D2.1, R17.2
unnamed: D3.1, R21.2
unnamed: D4.1, R26.2
unnamed: D5.1, R35.2
unnamed: D6.1, R42.2
unnamed: C9.1, D9.2 (A), L1.2, R46.1, R48.2
unnamed: D12.1, R69.2
unnamed: D13.1, R70.2
unnamed: K2.1, RLY_NC1.1
unnamed: K2.5, K2.6, RLY_CM1.1
unnamed: K2.10, RLY_NO1.1
unnamed: Q2.3 (D), R19.2, R20.2, R24.2
unnamed: Q2.1 (G), R24.1, R25.2
unnamed: Q5.3 (D), R29.2, R31.2, R32.2
unnamed: Q5.1 (G), R32.1, R34.2
unnamed: Q6.3 (D), R30.2, R33.2, R38.2
unnamed: Q6.1 (G), R38.1, R39.2
unnamed: Q7.3 (D), R39.1
unnamed: Q8.3 (D), R25.1
unnamed: Q9.3 (D), R34.1
unnamed: Q10.3 (D), R66.1
unnamed: Q13.3 (D), R57.2, R60.2, R65.2
unnamed: Q13.1 (G), R65.1, R66.2
unnamed: R1.2, R7.1, SW1.1
unnamed: R2.2, R8.1, SW2.1
unnamed: R3.2, R9.1, SW3.1
unnamed: R4.2, R10.1, SW4.1
unnamed: R5.2, R11.1, SW5.1
unnamed: R6.2, R12.1, SW6.1
unnamed: R45.1, U2.4 (*SHDN)
unnamed: R46.2, R47.1, U2.3 (FB)
unnamed: C8.2, L1.1, U1.1, U2.6 (SW)

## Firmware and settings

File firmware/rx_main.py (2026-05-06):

"""
Wireless Switch – RECEIVER firmware
Raspberry Pi Pico 2 W  |  Hardware v2  |  WiFi branch

GPIO  0  CONNECTED LED  – solid ON when link is up
GPIO  7  SEARCHING LED  – flashes while searching, OFF when linked
GPIO  8-11  MOSFET outputs CH1-CH4 (up to 5 A each)
GPIO 12     Relay K2 output CH5

Link-loss behaviour:
  - Outputs hold their last state for HOLD_MS (default 10 s)
  - After hold period, all outputs turn off

Channel modes (configurable via web interface):
  - MODE_MOMENTARY: output follows switch state
  - MODE_LATCH:     each press toggles output ON/OFF

Web interface: http://<RX-IP>
  RX IP is shown as a clickable link on the TX settings page (http://192.168.4.1).
"""

import network
import socket
import time
import ujson
from machine import Pin, reset
import config

# -- Flash config (loaded before hardware init) ---------------
PAIR_ID       = config.PAIR_ID
WIFI_SSID     = config.WIFI_SSID
HOLD_MS       = config.HOLD_ON_DISCONNECT_MS
CHANNEL_MODES = list(config.CHANNEL_MODES)   # mutable local copy

try:
    with open("user_config.json") as _f:
        _cfg = ujson.load(_f)
    PAIR_ID   = int(_cfg.get("pair_id", PAIR_ID))
    WIFI_SSID = "WirelessSwitch-{}".format(PAIR_ID)
    HOLD_MS   = int(_cfg.get("hold_time_s", HOLD_MS // 1000)) * 1000
    _m = _cfg.get("channel_modes")
    if isinstance(_m, list) and len(_m) == len(CHANNEL_MODES):
        for _i in range(len(CHANNEL_MODES)):
            CHANNEL_MODES[_i] = int(_m[_i])
except Exception:
    pass

# -- Hardware -------------------------------------------------
connected_led = Pin(config.GPIO_CONNECTED, Pin.OUT, value=0)
searching_led = Pin(config.GPIO_SEARCHING, Pin.OUT, value=0)
outputs       = [Pin(gp, Pin.OUT, value=0) for gp in config.RX_OUTPUT_GPIOS]

# -- Channel state --------------------------------------------
_prev_raw  = [0] * len(config.RX_OUTPUT_GPIOS)
_latch_out = [0] * len(config.RX_OUTPUT_GPIOS)


def blink_error():
    while True:
        connected_led.toggle()
        searching_led.toggle()
        time.sleep_ms(100)


def all_outputs_off():
    for out in outputs:
        out.value(0)
    for i in range(len(_latch_out)):
        _latch_out[i] = 0


def apply_states(raw):
    """Apply received switch states honouring per-channel mode."""
    for i in range(len(outputs)):
        if CHANNEL_MODES[i] == config.MODE_MOMENTARY:
            outputs[i].value(raw[i])
        else:                                        # MODE_LATCH
            if raw[i] == 1 and _prev_raw[i] == 0:   # rising edge → toggle
                _latch_out[i] ^= 1
            outputs[i].value(_latch_out[i])
        _prev_raw[i] = raw[i]


def parse_packet(data):
    if len(data) < 7 or data[0] != 0xAA:
        return None
    states = list(data[1:6])
    if sum(states) & 0xFF != data[6]:
        return None
    return states


def save_config():
    with open("user_config.json", "w") as f:
        ujson.dump({
            "pair_id":       PAIR_ID,
            "hold_time_s":   HOLD_MS // 1000,
            "channel_modes": CHANNEL_MODES,
        }, f)


# -- Web interface --------------------------------------------
_CSS = (
    b"body{font-family:system-ui,sans-serif;padding:16px;max-width:500px;margin:0 auto}"
    b"h2{margin:0 0 10px}h3{margin:14px 0 6px}"
    b".ok{background:#d4edda;color:#155724;padding:8px;border-radius:6px;margin:8px 0}"
    b".srch{background:#fff3cd;color:#856404;padding:8px;border-radius:6px;margin:8px 0}"
    b"table{width:100%;border-collapse:collapse;margin:6px 0}"
    b"td,th{padding:7px 10px;border:1px solid #dee2e6;font-size:.9em}"
    b"th{background:#f1f3f5;font-weight:600}"
    b"label{display:block;font-weight:500;margin:10px 0 3px}"
    b"input,select{width:100%;padding:8px;border:1px solid #ced4da;border-radius:4px;"
    b"box-sizing:border-box;font-size:1em}"
    b"button{width:100%;padding:11px;background:#0d6efd;color:#fff;border:none;"
    b"border-radius:4px;margin-top:10px;font-size:1em;cursor:pointer}"
    b".warn{background:#fff3cd;border:1px solid #ffc107;border-radius:4px;"
    b"padding:8px;font-size:.85em;margin:8px 0}"
)

_HEAD = (
    b"HTTP/1.0 200 OK\r\nContent-Type: text/html\r\n\r\n"
    b"<!DOCTYPE html><html><head>"
    b"<meta name=viewport content='width=device-width,initial-scale=1'>"
    b"<title>RX Settings</title>"
    b"<style>"
)

_MODE_LABELS = [b"Momentary", b"Latch"]


def _parse_form(body):
    params = {}
    for part in body.split(b"&"):
        if b"=" in part:
            k, v = part.split(b"=", 1)
            params[k.strip()] = v.strip()
    return params


def _current_out_state(i):
    if CHANNEL_MODES[i] == config.MODE_LATCH:
        return _latch_out[i]
    return outputs[i].value()


def _serve_rx(cl, link_ok):
    w = cl.write
    w(_HEAD + _CSS + b"</style></head><body>")
    w(b"<h2>RX &ndash; " + WIFI_SSID.encode() + b"</h2>")
    w(b"<p><a href='http://192.168.4.1/'>&#8592; TX Settings</a></p>")
    w(b"<div class=ok>&#10003; Linked to TX</div>" if link_ok
      else b"<div class=srch>&#9679; Searching for TX&hellip;</div>")

    # Output states table
    w(b"<h3>Output States</h3>")
    w(b"<table><tr><th>Channel</th><th>GPIO</th><th>Mode</th><th>State</th></tr>")
    for i, (name, gp) in enumerate(zip(config.CHANNEL_NAMES, config.RX_OUTPUT_GPIOS)):
        state = _current_out_state(i)
        w(b"<tr><td>" + name.encode() + b"</td><td>" + str(gp).encode() +
          b"</td><td>" + _MODE_LABELS[CHANNEL_MODES[i]] +
          b"</td><td>" + (b"<b>ON</b>" if state else b"off") + b"</td></tr>")
    w(b"</table>")

    # Settings form
    w(b"<form method=post action=/save>")

    w(b"<h3>Settings</h3>")
    w(b"<label>Pair ID (1&ndash;99):</label>")
    w(b"<input type=number name=pair_id value=" + str(PAIR_ID).encode() +
      b" min=1 max=99>")
    w(b"<div class=warn>&#9888; Changing Pair ID connects this board to a different TX."
      b" Update TX Pair ID first, then save here.</div>")

    w(b"<label>Hold time on disconnect (0&ndash;60 seconds):</label>")
    w(b"<input type=number name=hold_time_s value=" + str(HOLD_MS // 1000).encode() +
      b" min=0 max=60>")

    # Channel mode selects
    w(b"<h3>Channel Modes</h3>")
    w(b"<table><tr><th>Channel</th><th>Mode</th></tr>")
    for i, name in enumerate(config.CHANNEL_NAMES):
        key = ("ch%d_mode" % i).encode()
        sel_m = b" selected" if CHANNEL_MODES[i] == 0 else b""
        sel_l = b" selected" if CHANNEL_MODES[i] == 1 else b""
        w(b"<tr><td>" + name.encode() + b"</td><td>"
          b"<select name=" + key + b">"
          b"<option value=0" + sel_m + b">Momentary (ON while held)</option>"
          b"<option value=1" + sel_l + b">Latch (toggle ON/OFF)</option>"
          b"</select></td></tr>")
    w(b"</table>")

    w(b"<button>Save Settings</button>")
    w(b"</form>")
    w(b"<p style='color:#6c757d;font-size:.8em;margin-top:20px'>Firmware v" +
      config.FIRMWARE_VERSION.encode() + b" &ndash; RX</p>")
    w(b"</body></html>")


def handle_web_rx(web_sock, link_ok):
    global PAIR_ID, WIFI_SSID, HOLD_MS, CHANNEL_MODES
    try:
        cl, _ = web_sock.accept()
    except OSError:
        return
    try:
        cl.settimeout(0.5)
        req = cl.recv(1024)
        # Body often arrives in a second TCP packet — read it if missing
        if req.startswith(b"POST") and b"\r\n\r\n" in req:
            body = req.split(b"\r\n\r\n", 1)[1]
            if not body:
                try:
                    body = cl.recv(512)
                except OSError:
                    body = b""
        elif req.startswith(b"POST"):
            body = b""

        if req.startswith(b"POST"):
            params = _parse_form(body)
            need_reset = False

            if b"pair_id" in params:
                try:
                    new_id = int(params[b"pair_id"])
                    if 1 <= new_id <= 99 and new_id != PAIR_ID:
                        PAIR_ID   = new_id
                        WIFI_SSID = "WirelessSwitch-{}".format(PAIR_ID)
                        need_reset = True
                except Exception:
                    pass

            if b"hold_time_s" in params:
                try:
                    new_hold = int(params[b"hold_time_s"])
                    HOLD_MS = max(0, min(60, new_hold)) * 1000
                except Exception:
                    pass

            for i in range(len(CHANNEL_MODES)):
                key = ("ch%d_mode" % i).encode()
                if key in params:
                    try:
                        CHANNEL_MODES[i] = int(params[key])
                    except Exception:
                        pass

            save_config()
            cl.write(b"HTTP/1.0 303 See Other\r\nLocation: /\r\n\r\n")
            cl.close()
            if need_reset:
                time.sleep_ms(300)
                reset()
        else:
            _serve_rx(cl, link_ok)
    except Exception as e:
        print("[WEB]", e)
    finally:
        try:
            cl.close()
        except Exception:
            pass


# -- WiFi STA -------------------------------------------------
def connect_wifi():
    for _ in range(3):
        searching_led.value(1)
        time.sleep_ms(150)
        searching_led.value(0)
        time.sleep_ms(150)

    sta = network.WLAN(network.STA_IF)
    sta.active(True)
    print("[RX] Connecting to", WIFI_SSID)

    deadline     = time.ticks_add(time.ticks_ms(), 60_000)
    last_attempt = time.ticks_add(time.ticks_ms(), -10_000)

    while not sta.isconnected():
        now = time.ticks_ms()
        if time.ticks_diff(now, last_attempt) >= 5_000:
            print("[RX] Trying connect…")
            try:
                sta.connect(WIFI_SSID)
            except OSError:
                pass
            last_attempt = now
        searching_led.toggle()
        if time.ticks_diff(deadline, now) <= 0:
            return None
        time.sleep_ms(250)

    searching_led.value(0)
    ip = sta.ifconfig()[0]
    print("[RX] Connected –", sta.ifconfig())
    print("[RX] Web interface: http://{}/".format(ip))
    return sta


def main():
    sta = connect_wifi()
    if sta is None:
        print("[RX] WiFi connect timed out")
        blink_error()

    tx_addr = (config.TX_HOST, config.UDP_PORT)

    udp = socket.socket(socket.AF_INET, socket.SOCK_DGRAM)
    udp.bind(("0.0.0.0", config.UDP_PORT))
    udp.settimeout(0.1)

    web = socket.socket(socket.AF_INET, socket.SOCK_STREAM)
    web.setsockopt(socket.SOL_SOCKET, socket.SO_REUSEADDR, 1)
    web.bind(("0.0.0.0", config.WEB_PORT))
    web.listen(1)
    web.setblocking(False)

    # Start past the hold window so outputs are OFF at boot
    last_rx_time      = time.ticks_add(time.ticks_ms(), -(config.LINK_TIMEOUT_MS + 1))
    last_link_ok_t    = time.ticks_add(time.ticks_ms(), -(HOLD_MS + 1))
    search_flash_t    = time.ticks_ms()
    last_reconnect_t  = time.ticks_add(time.ticks_ms(), -10_000)
    link_ok           = False

    print("[RX] Listening for TX packets…")

    while True:
        now = time.ticks_ms()

        # Web request (non-blocking)
        handle_web_rx(web, link_ok)

        # Heartbeat to TX
        try:
            udp.sendto(b"RXHERE", tx_addr)
        except OSError:
            pass

        # Receive switch-state packet
        try:
            data, _ = udp.recvfrom(32)
            states  = parse_packet(data)
            if states is not None:
                apply_states(states)
                last_rx_time = now
        except OSError:
            pass

        # Link status
        link_ok = time.ticks_diff(now, last_rx_time) < config.LINK_TIMEOUT_MS

        if link_ok:
            connected_led.value(1)
            searching_led.value(0)
            last_link_ok_t = now
        else:
            connected_led.value(0)
            # Hold outputs for HOLD_MS after link loss, then release
            if time.ticks_diff(now, last_link_ok_t) >= HOLD_MS:
                all_outputs_off()
            if time.ticks_diff(now, search_flash_t) >= config.SEARCH_FLASH_MS:
                searching_led.toggle()
                search_flash_t = now
            if not sta.isconnected():
                if time.ticks_diff(now, last_reconnect_t) >= 5_000:
                    print("[RX] WiFi lost – reconnecting…")
                    try:
                        sta.active(False)
                        time.sleep_ms(100)
                        sta.active(True)
                        sta.connect(WIFI_SSID)
                    except OSError:
                        pass
                    last_reconnect_t = now

        time.sleep_ms(config.HEARTBEAT_MS)


try:
    main()
except Exception as e:
    print("[RX] CRASH:", e)
    blink_error()

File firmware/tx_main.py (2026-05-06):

"""
Wireless Switch – TRANSMITTER firmware
Raspberry Pi Pico 2 W  |  Hardware v2  |  WiFi branch

GPIO 0  CONNECTED LED  – solid ON when RX is linked
GPIO 7  SEARCHING LED  – flashes while waiting for RX, OFF when linked
GPIO 1-5  Switch inputs (active-low, internal pull-up)

Web interface: http://192.168.4.1
  Connect phone/laptop to the WirelessSwitch-N WiFi network, then open that URL.
"""

import network
import socket
import time
import ujson
from machine import Pin, reset
import config

# -- Flash config (loaded before hardware init) ---------------
# Overrides config.py defaults with values saved via the web UI.
PAIR_ID   = config.PAIR_ID
WIFI_SSID = config.WIFI_SSID

try:
    with open("user_config.json") as _f:
        _cfg = ujson.load(_f)
    PAIR_ID   = int(_cfg.get("pair_id", PAIR_ID))
    WIFI_SSID = "WirelessSwitch-{}".format(PAIR_ID)
except Exception:
    pass

# -- Hardware -------------------------------------------------
connected_led = Pin(config.GPIO_CONNECTED, Pin.OUT, value=0)
searching_led = Pin(config.GPIO_SEARCHING, Pin.OUT, value=0)
switches      = [Pin(gp, Pin.IN, Pin.PULL_UP) for gp in config.TX_SWITCH_GPIOS]


def blink_error():
    while True:
        connected_led.toggle()
        searching_led.toggle()
        time.sleep_ms(100)


def read_switches():
    return [1 - sw.value() for sw in switches]


def build_packet(states):
    chk = sum(states) & 0xFF
    return bytes([0xAA] + states + [chk])


def save_config():
    with open("user_config.json", "w") as f:
        ujson.dump({"pair_id": PAIR_ID}, f)


# -- Web interface --------------------------------------------
_CSS = (
    b"body{font-family:system-ui,sans-serif;padding:16px;max-width:500px;margin:0 auto}"
    b"h2{margin:0 0 10px}h3{margin:14px 0 6px}"
    b".ok{background:#d4edda;color:#155724;padding:8px;border-radius:6px;margin:8px 0}"
    b".srch{background:#fff3cd;color:#856404;padding:8px;border-radius:6px;margin:8px 0}"
    b"table{width:100%;border-collapse:collapse;margin:6px 0}"
    b"td,th{padding:7px 10px;border:1px solid #dee2e6;font-size:.9em}"
    b"th{background:#f1f3f5;font-weight:600}"
    b"label{display:block;font-weight:500;margin:10px 0 3px}"
    b"input{width:100%;padding:8px;border:1px solid #ced4da;border-radius:4px;"
    b"box-sizing:border-box;font-size:1em}"
    b"button{width:100%;padding:11px;background:#0d6efd;color:#fff;border:none;"
    b"border-radius:4px;margin-top:10px;font-size:1em;cursor:pointer}"
    b".warn{background:#fff3cd;border:1px solid #ffc107;border-radius:4px;"
    b"padding:8px;font-size:.85em;margin:8px 0}"
    b"a{color:#0d6efd}"
)

_HEAD = (
    b"HTTP/1.0 200 OK\r\nContent-Type: text/html\r\n\r\n"
    b"<!DOCTYPE html><html><head>"
    b"<meta name=viewport content='width=device-width,initial-scale=1'>"
    b"<title>TX Settings</title>"
    b"<style>"
)


def _parse_form(body):
    params = {}
    for part in body.split(b"&"):
        if b"=" in part:
            k, v = part.split(b"=", 1)
            params[k.strip()] = v.strip()
    return params


def _serve_tx(cl, link_ok, rx_addr, sw_states):
    w = cl.write
    w(_HEAD + _CSS + b"</style></head><body>")
    w(b"<h2>TX &ndash; " + WIFI_SSID.encode() + b"</h2>")

    if link_ok and rx_addr:
        rx_ip = rx_addr[0].encode()
        w(b"<div class=ok>&#10003; Linked &ndash; RX at " + rx_ip + b"</div>")
        w(b"<p><a href='http://" + rx_ip + b"/'>Open RX settings &rarr;</a></p>")
    else:
        w(b"<div class=srch>&#9679; Searching for RX&hellip;</div>")

    w(b"<h3>Switch States</h3>")
    w(b"<table><tr>")
    for i in range(len(config.TX_SWITCH_GPIOS)):
        w(b"<th>SW" + str(i + 1).encode() + b"</th>")
    w(b"</tr><tr>")
    for s in sw_states:
        w(b"<td><b>ON</b></td>" if s else b"<td>off</td>")
    w(b"</tr></table>")

    w(b"<h3>Settings</h3>")
    w(b"<form method=post action=/save>")
    w(b"<label>Pair ID (1&ndash;99):</label>")
    w(b"<input type=number name=pair_id value=" + str(PAIR_ID).encode() +
      b" min=1 max=99>")
    w(b"<div class=warn>&#9888; Changing Pair ID renames the WiFi network and reboots"
      b" this board. Update the RX Pair ID first, then save here.</div>")
    w(b"<button>Save &amp; Reboot TX</button>")
    w(b"</form>")
    w(b"<p style='color:#6c757d;font-size:.8em;margin-top:20px'>Firmware v" +
      config.FIRMWARE_VERSION.encode() + b" &ndash; TX</p>")
    w(b"</body></html>")


def handle_web_tx(web_sock, link_ok, rx_addr, sw_states):
    global PAIR_ID, WIFI_SSID
    try:
        cl, _ = web_sock.accept()
    except OSError:
        return
    try:
        cl.settimeout(0.5)
        req = cl.recv(1024)

        if req.startswith(b"POST"):
            body = req.split(b"\r\n\r\n", 1)[-1] if b"\r\n\r\n" in req else b""
            params = _parse_form(body)
            if b"pair_id" in params:
                try:
                    new_id = int(params[b"pair_id"])
                    if 1 <= new_id <= 99:
                        PAIR_ID   = new_id
                        WIFI_SSID = "WirelessSwitch-{}".format(PAIR_ID)
                        save_config()
                        cl.write(b"HTTP/1.0 303 See Other\r\nLocation: /\r\n\r\n")
                        cl.close()
                        time.sleep_ms(300)
                        reset()
                except Exception:
                    pass
            cl.write(b"HTTP/1.0 303 See Other\r\nLocation: /\r\n\r\n")
        else:
            _serve_tx(cl, link_ok, rx_addr, sw_states)
    except Exception as e:
        print("[WEB]", e)
    finally:
        try:
            cl.close()
        except Exception:
            pass


# -- WiFi AP --------------------------------------------------
def start_ap():
    for _ in range(3):
        searching_led.value(1)
        time.sleep_ms(150)
        searching_led.value(0)
        time.sleep_ms(150)

    ap = network.WLAN(network.AP_IF)
    try:
        ap.active(False)
        time.sleep_ms(500)
    except OSError:
        pass
    ap.config(ssid=WIFI_SSID, security=0, password="")
    ap.active(True)

    deadline = time.ticks_add(time.ticks_ms(), 15_000)
    while not ap.active():
        searching_led.toggle()
        if time.ticks_diff(deadline, time.ticks_ms()) <= 0:
            return None
        time.sleep_ms(200)

    searching_led.value(0)
    print("[TX] AP:", WIFI_SSID, " IP:", ap.ifconfig()[0])
    print("[TX] Web interface: http://192.168.4.1/")
    return ap
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

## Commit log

2026-04-20 Add files via upload
    Kicad files for PWB that went to fab
2026-05-03 Add hardware-v2 branch: GPIO reassignment + firmware + docs
    KiCad schematic (based on existing wireless_switch design):
    - Added GPIO mapping annotation to top-level schematic
    - GPIO 0 : CONNECTED LED (both TX and RX)
    - GPIO 7 : SEARCHING LED - flashes while searching, OFF when linked
    - GPIO 1-5: Transmitter switch inputs (active-low)
    - GPIO 8-11: Receiver MOSFET outputs CH1-CH4 (5 A each)
    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
    [Pico_interface.kicad_sch, analog_in.kicad_sch, input_power.kicad_sch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]
2026-05-03 Add .gitignore for extracted design dir and KiCad artifacts
    https://claude.ai/code/session_016QqQ78B9vQB467ZraMVFxw
2026-05-03 Add Windows batch scripts for install and verification (COM3/COM5)
    - install_tx.bat : installs TX firmware, defaults to COM3
    - install_rx.bat : installs RX firmware, defaults to COM5
    - verify.bat : end-to-end check of both devices - tests MicroPython,
    config, GPIO init, LED toggles, output channel pulses,
    and WiFi chip presence on TX (COM3) and RX (COM5)
    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
2026-05-03 Add LED visibility and polarity test scripts
    - led_test.bat : blinks GPIO 0 and GPIO 7 on both boards simultaneously,
    10 x 500ms flashes so they are clearly visible
    - polarity_test.bat: interactive test to determine active-high vs active-low
    wiring and locate the actual GPIO if it differs from config
    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
2026-05-03 Fix TX AP SSID not being applied on boot
    ap.config() must be called before ap.active(True), not after.
    Activating the AP first causes MicroPython to use the default
    board SSID (PICOFA2C). Also use authmode=3 integer directly
    to avoid any AUTH_WPA2_PSK constant lookup issues.
    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
    [tx_main.py]
2026-05-03 Fix RX searching LED staying ON after WiFi connect; clean up LED logic
    - Remove incorrect active-low LED_ON/LED_OFF constants (LEDs are active-high)
    - Fix last_rx_time init bug: was set to now() causing link_ok=True on first
    tick before any UDP packet received, leaving searching LED in wrong state.
    Now initialised LINK_TIMEOUT_MS in the past so RX starts in searching state
    and only transitions to connected when a real packet arrives from TX.
    - Replace search_led_state bool toggle with searching_led.toggle() in both
    tx_main and rx_main - simpler and polarity-independent
    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
    [rx_main.py, tx_main.py]
2026-05-03 Fix TX LEDs never lighting; add startup blink and crash handler
    - Remove ap.active(False) before ap.config() - caused silent exception on
    Pico W MicroPython v1.27 which killed firmware before any LED code ran
    - Blink searching LED 3x immediately at startup so user can confirm
    firmware is running before WiFi init
    - Flash searching LED during AP startup instead of after
    - Add blink_error() fast-flash pattern for fatal errors
    - Wrap main() in try/except so crashes show as fast LED blink not dark board
    - Use security= instead of authmode= (correct kwarg for cyw43 driver)
    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
    [tx_main.py]
2026-05-03 Fix RX WiFi never connecting; add startup blink and crash handler
    - connect_wifi() was calling sta.connect() every 500ms in a loop, constantly
    interrupting its own connection handshake. Now calls connect() once then
    waits up to 30 seconds for sta.isconnected() to become True.
    - Add 3-blink startup confirmation (same as TX) so user can see firmware running
    - Add 30 s WiFi timeout returning None so caller can signal error via blink_error()
    - Add blink_error() fast-flash for fatal crashes
    - Wrap main() in try/except so any unhandled exception shows as fast LED blink
    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
    [rx_main.py]
2026-05-03 Switch to open WiFi network (no password)
    The security= parameter in ap.config() was silently ignored by the cyw43
    driver on MicroPython v1.27, leaving the AP open. The RX and phone were
    both trying to authenticate against an open AP, causing connection failure.
    Open network is appropriate for a race car - no authentication overhead,
    faster reconnect, shorter range means no external interference risk.
    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
    [rx_main.py, tx_main.py]
2026-05-03 Force AP to open: deactivate before config to clear old WPA2 password
    The Pico W WiFi chip retains previous security settings across reboots.
    Without ap.active(False) first, ap.config(security=0) had no effect and
    the AP kept broadcasting with WPA2 requiring the old password.
    Fix: wrap ap.active(False) in try/except so it can't crash the firmware,
    then explicitly set security=0 and password='' before reactivating.
    Also: RX connect_wifi() now retries sta.connect() every 5 s with a 60 s
    total timeout instead of a single attempt, so it survives TX AP startup lag.
    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
    [rx_main.py, tx_main.py]
2026-05-05 Add web UI, hold-on-disconnect, latch modes, and PAIR_ID to WiFi branch
    Web interface (HTTP port 80):
    TX: http://192.168.4.1 -- shows switch states, link status, PAIR_ID form
    RX: http://<RX-IP> -- shows output states, hold time, channel mode selects
    TX page links directly to RX page when connected.
    Settings saved to user_config.json on flash; persist across reboots.
    PAIR_ID isolates multiple TX/RX pairs. WIFI_SSID derived as
    "WirelessSwitch-{PAIR_ID}". Changing PAIR_ID on TX reboots and renames the AP;
    RX saves and reboots to connect to the new SSID.
    Hold-on-disconnect: RX holds last output states for HOLD_MS (default 10 s)
    before releasing on link loss. Configurable 0-60 s via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
    [rx_main.py, tx_main.py]
2026-05-06 Fix RX reconnect, POST body parsing, and add TX back-link
    - Reconnect: limit WiFi retry to every 5 s with interface reset
    (active False/True) so TX power-cycle triggers clean reconnect
    - POST body: do a second recv() when body is missing from first
    packet, fixing settings not saving on most browsers
    - Web UI: add back-link to http://192.168.4.1/ on RX settings page
    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
    [rx_main.py]
